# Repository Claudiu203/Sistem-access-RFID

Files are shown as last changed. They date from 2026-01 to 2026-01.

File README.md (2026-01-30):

# 🔐 Sistem de acces cu RFID (RFID Access Control System)

## 📌 Descriere generală

Acest proiect implementează un **sistem embedded de control al accesului în doi pași**, bazat pe:
- **card RFID**
- **cod PIN introdus prin tastatură 4×4**

Sistemul este realizat pe platforma **FRDM-KL25Z** și oferă autentificare sigură, feedback vizual în timp real și acționare fizică a unui mecanism de blocare. Proiectul demonstrează integrarea mai multor periferice hardware într-o arhitectură embedded modulară și scalabilă.

---

## 🎯 Obiectivele proiectului

- Implementarea unui sistem de control al accesului bazat pe **RFID + PIN**
- Integrarea interfețelor hardware: **SPI, I2C, UART, GPIO**
- Afișarea informațiilor de stare pe **OLED**
- Controlul unui **electromagnet** pentru blocare/deblocare
- Utilizarea temporizărilor neblocante prin **SysTick**
- Extinderea sistemului cu **Wi-Fi** și **loguri de evenimente**

---

## 🧠 Arhitectura sistemului

Sistemul este construit în jurul microcontrolerului **FRDM-KL25Z**, care coordonează toate modulele hardware.

### Componente hardware principale

| Componentă | Rol |
|---|-----|
| FRDM-KL25Z | Microcontroler (MCU) |
| RFID MFRC522 | Citire carduri RFID |
| Tastatură 4×4 | Introducere cod PIN |
| OLED SSD1306 | Interfață vizuală |
| LED roșu / verde | Semnalizare stare |
| Electromagnet + MOSFET | Mecanism de blocare |
| Buton fizic | Acces manual |
| Modul Wi-Fi (ESP8266) | Monitorizare în rețea |
| Modul microSD | Stocare loguri |

---

## 🔌 Interfețe utilizate

| Interfață | Componentă |
|---|---|
| SPI | RFID MFRC522, microSD |
| I2C | OLED SSD1306 |
| UART | FRDM ↔ Arduino ↔ ESP8266 |
| GPIO | Tastatură, LED-uri, electromagnet |
| SysTick | Temporizări neblocante |

---

## 🔑 Fluxul de autentificare

1. Utilizatorul apropie cardul RFID
2. UID-ul este citit și validat
3. Pe OLED apare mesajul **„Introduceți PIN”**
4. Utilizatorul introduce PIN-ul pe tastatură
5. PIN-ul este afișat în timp real
6. Sistemul validează **UID + PIN**
7. Dacă autentificarea reușește:
   - LED verde ON
   - electromagnet activ
8. După timeout → revenire în starea de repaus

---

## 🖥️ Interfața cu utilizatorul

- **OLED** – mesaje de stare (`PIN OK`, `PIN WRONG`)
- **LED verde** – acces permis
- **LED roșu** – acces blocat
- **Tastatură 4×4**
  - Cifre: introducere PIN
  - `A`: RESET PIN
  - `C`: ENTER / confirmare

---

## 🌐 Monitorizare prin Wi-Fi

Sistemul transmite mesaje de stare prin UART către un Arduino, care:
- controlează un modul **ESP8266**
- rulează un **server web local**
- afișează logurile de acces într-o pagină HTML

Funcționalități:
- monitorizare în timp real
- acces din browser
- fără servicii cloud externe

---

## 🧱 Design mecanic

Carcasa sistemului a fost proiectată în **Autodesk Fusion 360** și include:
- suport pentru placa FRDM-KL25Z
- decupaje pentru OLED, tastatură și cititor RFID
- organizare ergonomică a interfeței utilizator

Designul permite montaj stabil, mentenanță ușoară și un aspect compact.

---

## ⚙️ Tehnologii utilizate

- Limbaj: **C (bare-metal)**
- Platformă: **FRDM-KL25Z**
- CAD: **Autodesk Fusion 360**
- Comunicație: SPI, I2C, UART
- Temporizare: SysTick
- Rețea: ESP8266 (AT Commands)

---
## 👥 Autori

- Claudiu Acosti  
- Cristina Lupescu  
- Mircea Ivescu  
- Bianca Ciobanu  

**Academia Tehnică Militară „Ferdinand I” – București**

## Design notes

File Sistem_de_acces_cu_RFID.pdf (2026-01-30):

# Sistem de acces cu RFID

Claudiu Acosti
Facultatea de Sisteme Informatice ¸si Securitate Cibernetic˘a Academia Tehnic˘a Militar˘a „Ferdinand I” Bucure¸sti, România
claudiu.acosti@mta.ro

Cristina Lupescu
Facultatea de Sisteme Informatice ¸si Securitate Cibernetic˘a Academia Tehnic˘a Militar˘a „Ferdinand I” Bucure¸sti, România
cristina.lupescu@mta.ro

Mircea Ivescu
Facultatea de Sisteme Informatice ¸si Securitate Cibernetic˘a Academia Tehnic˘a Militar˘a „Ferdinand I” Bucure¸sti, România
mircea.ivescu@mta.ro

Bianca Ciobanu
Facultatea de Sisteme Informatice ¸si Securitate Cibernetic˘a Academia Tehnic˘a Militar˘a „Ferdinand I” Bucure¸sti, România
bianca.ciobanu@mta.ro

Rezumat—Acest proiect prezinta dezvoltarea unui sistem elec- ˘ tronic inteligent de control al accesului, realizat pe platforma FRDM-KL25Z s,

i bazat pe identificare prin radiofrecvent,a˘
(RFID). Sistemul utilizeaza un modul RFID pentru citirea s ˘ | | | , i
autentificarea cardurilor, completat de o tastatura 4×4 pentru ˘ introducerea unui cod PIN secundar, crescând astfel nivelul de securitate printr-o verificare în doi pas,
i. Cifrele introduse de
utilizator prin tastatura sunt afis ˘ | ,ate în timp real pe un ecran
OLED, care este folosit s,

i pentru prezentarea mesajelor de stare s,

i a interfet,ei cu utilizatorul, facilitând operarea s,
i diagnosticarea
sistemului. Doua LED-uri asigur ˘ | a semnalizarea vizual ˘ | a rapid ˘ | a˘
asupra validitat˘ ,

ii autentificarii (acces permis / acces refuzat). ˘ Mecanismul fizic de blocare este implementat cu ajutorul unui electromagnet, activat numai dupa validarea cu succes a cardului ˘ RFID s,

i a codului PIN.
Pentru extinderea funct, | ionalitat˘ ,
ilor, proiectul include un mo-
dul Wi-Fi, ce permite transmiterea datelor catre o ret ˘ | ,ea locala˘
sau infrastructura cloud pentru monitorizarea accesului în timp ˘ real, precum s,

i un modul microSD pentru stocarea locala a ˘ logurilor de evenimente. Integrarea acestor componente conduce la un sistem modular, scalabil s,

i eficient energetic, reprezentând o solut,

ie moderna s ˘ ,

i sigura de control al accesului pentru aplicat ˘ | ,
| | | ii
rezident,

iale s,

i industriale. Pentru vizualizarea proiectului prezentat se poate accesa https://github.com/Claudiu203/Sistem-access-RFID.
Index Terms—RFID, controlul accesului, sisteme embedded, FRDM-KL25Z, securitate.
I. INTRODUCERE

Sistemele moderne de control al accesului reprezinta o ˘
componenta esent ˘ | ,
iala în cres ˘ | ,
terea nivelului de securitate pentru
cladiri, laboratoare, zone industriale sau spat ˘ | ,
ii rezident,

iale.
În contextul dezvoltarii accelerate a tehnologiilor embedded ˘ s,

i IoT, solut,

iile de identificare inteligenta devin tot mai ac- ˘ cesibile, mai flexibile s,

i mai sigure. Una dintre tehnologiile
utilizate pe scara larg ˘ | a este identificarea prin radiofrecvent ˘ | ,a˘
(RFID), care permite autentificarea rapida s ˘ ,

i far˘ a contact a ˘
utilizatorilor, asigurând un nivel ridicat de confort s,
| | i fiabilitate.
Proiectul de fat,a propune realizarea unui sistem electronic ˘ integrat de control al accesului utilizând platforma FRDM-KL25Z, un microcontroler performant s,
| | i versatil, potrivit
Acronim | Denumire
RFID | Radio Frequency Identification
PIN | Personal Identification Number
OLED | Organic Light Emitting Diode
LED | Light Emitting Diode
MCU | Microcontroller Unit
SPI | Serial Peripheral Interface
I2C | Inter-Integrated Circuit
UART | Universal Asynchronous Receiver-Transmitter
GPIO | General Purpose Input/Output
UID | Unique Identifier
SD | Secure Digital
Wi-Fi | Wireless Fidelity
FRDM | Freedom Development Platform
MOSFET | Metal-Oxide-Semiconductor Field-Effect Transistor
SysTick | System Timer Tick
Tabela I
LISTA ACRONIMELOR UTILIZATE

aplicat,

iilor embedded de nivel mediu-complex. Sistemul com-
bina autentificarea pe baz ˘ | a de card RFID cu introducerea unui ˘
cod PIN prin intermediul unei tastaturi 4×4, asigurând un mecanism de securitate în doi pas,
i. Pentru interact,

iunea cu
utilizatorul, un afis, aj OLED este utilizat atât pentru vizualizarea în timp real a cifrelor introduse, cât s,

i pentru afis, area
mesajelor s,

i starilor sistemului. ˘

Elementele hardware auxiliare, precum LED-urile de semnalizare s,

i electromagnetul utilizat pentru mecanismul de
blocare, completeaza partea funct ˘ | ,

ionala a sistemului, oferind ˘ feedback vizual s,

i act,

ionare fizica a us ˘ ,

ii. În plus, integrarea
unui modul Wi-Fi permite transmiterea datelor de acces catre ˘ o ret,ea sau un server extern, facilitând monitorizarea de
la distant,a, iar modulul microSD ofer ˘ | a posibilitatea stoc ˘ | arii ˘
locale a logurilor s, | i a evenimentelor de securitate.

Prin combinat,

ia acestor componente, proiectul demonstreaza modul în care un sistem embedded poate implementa ˘ o solut,

ie moderna, sigur ˘ a s ˘ ,

i extensibila de control al accesului, ˘
adaptabila unei game largi de aplicat ˘ | ,
| ii practice.

A. Contextul general al temei

Controlul accesului în spat,

ii securizate reprezinta o nece- ˘
sitate tot mai importanta în contextul cres ˘ | ,
terii cerint,elor de
securitate fizica. Metodele tradit ˘ | ,
ionale bazate pe chei mecanice sau cartele simple prezinta limit ˘ ari semnificative, precum ˘ riscul de pierdere, copiere sau utilizare neautorizata. În plus, ˘ aceste solut,

ii nu ofera un mecanism eficient de monitorizare ˘ s,

i nici un feedback clar catre utilizator. ˘
În acest context, sistemele embedded de control al accesului,
bazate pe tehnologii far˘ a contact precum RFID s ˘ | ,
| | i autentificare
suplimentara prin cod PIN, devin solut ˘ | ,
ii moderne, flexibile s,

i
scalabile. Proiectul de fat,a se încadreaz ˘ | a în aceast ˘ | a categorie, ˘
propunând o implementare practica a unui sistem de acces ˘ inteligent, realizat pe platforma FRDM-KL25Z.
B. Motivat,ia alegerii proiectului
Alegerea acestui proiect a fost determinata de dorint ˘ | ,a
de a realiza un sistem embedded complet, care sa inte- ˘ greze mai multe tipuri de interfet,e hardware s,
| | i protocoale
de comunicat,
ie. Sistemul combina comunicat ˘ | ,
| | ii SPI (pentru
RFID), I2C (pentru OLED), GPIO (pentru tastatura, LED- ˘ uri, buton s,

i electromagnet) s,

i mecanisme de temporizare prin SysTick.
Proiectul ofera o imagine de ansamblu asupra modului în ˘ care un microcontroler poate coordona simultan mai multe periferice s,
i poate implementa o logica de securitate real ˘ | a,˘
utilizata în aplicat ˘ | ,
ii de control al accesului folosind exclusiv placuta frdm-kl25z.
C. Utilitatea solut,iei propuse

Solut,

ia propusa automatizeaz ˘ | a procesul de autentificare s ˘ | ,
i
acces, reducând intervent,
ia umana direct ˘ | a s ˘ ,
| | i crescând nivelul
de securitate. Sistemul permite accesul doar în urma validarii ˘ a doi factori: cardul RFID s,

i codul PIN introdus de utilizator. Feedback-ul este oferit prin LED-uri s,

| | i mesaje afis, ate pe
ecranul OLED, ceea ce îmbunat˘ at˘,es,
te experient,a de utilizare s,

i claritatea interact,

iunii.
Prin integrarea modulelor Wi-Fi s,

i microSD, sistemul poate
fi extins pentru monitorizarea accesului de la distant,a s ˘ , i
stocarea locala a evenimentelor, ceea ce îl face potrivit pentru ˘ aplicat,

ii reale.

D. Domenii de aplicare

Sistemul dezvoltat poate fi adaptat pentru multiple scenarii practice, precum:
- controlul accesului în cladiri de birouri sau institut ˘ | | , ii
publice;
- acces securizat în laboratoare universitare sau industriale;
- sisteme de acces pentru campusuri, camine sau zone ˘ rezident,

iale;
- integrarea în solut,

ii de tip smart home sau smart building.

E. Exemple de dispozitive similare

Sistemele comerciale moderne de control al accesului utilizeaza frecvent autentificarea prin card RFID sau tag NFC, ˘ combinata cu introducerea unui cod PIN pentru un nivel supli- ˘ mentar de securitate. În mediul educat,
ional s,

i de prototipare,
platforme precum Arduino, ESP32 sau placi din seria NXP ˘ FRDM sunt utilizate pentru dezvoltarea de sisteme similare, care includ cititoare RFID, tastaturi matriceale, afis, aje s,

i
mecanisme electromecanice de blocare.
F. Obiectivele proiectului

Principalele obiective ale proiectului sunt:
- proiectarea s,

i realizarea unui sistem embedded de control al accesului bazat pe RFID s,

i cod PIN;
- integrarea mai multor interfet,e hardware (SPI, I2C, GPIO) într-o aplicat,

ie unitara;˘
- implementarea unui mecanism de autentificare în doi pas,

i
(card + PIN);
- afis, area în timp real a informat,

iilor relevante pe un ecran OLED;
- realizarea unui sistem de semnalizare vizuala cu LED-uri ˘ pentru starea accesului;
- controlul unui electromagnet pentru blocarea/deblocarea mecanismului de acces;
- utilizarea temporizarilor neblocante prin intermediul ti- ˘ merului SysTick;
- posibilitatea extinderii sistemului prin conectivitate Wi-Fi s,

i stocare pe microSD.

II. ARHITECTURA S,
I DESIGNUL SISTEMULUI
Arhitectura sistemului de control al accesului este con-
ceputa într-o manier ˘ | a modular ˘ | a, pentru a facilita integrarea ˘
mai multor componente hardware distincte s,

i gestionarea lor
printr-un flux logic bine definit. Sistemul este construit în jurul microcontrolerului FRDM-KL25Z, care act,

ioneaza ca ˘
unitate centrala de control s ˘ | ,
i coordoneaza comunicat ˘ | ,
ia dintre
modulele periferice prin interfet,e precum SPI, I2C, UART s,

i
GPIO.
Structura aplicat,

iei este organizata pe straturi logice, in- ˘ cluzând: nivelul hardware, nivelul de abstractizare a driverelor, modulul de logic˘a aplicativ˘a s,

i interfat,a cu utilizatorul.
Aceasta abordare permite scalabilitate crescut ˘ | a, mentenant ˘ | ,a˘
us, oara s ˘ ,
i posibilitatea extinderii ulterioare cu funct,

ionalitat˘,
i
suplimentare.
A. Componentele majore ale sistemului
Sistemul este alcatuit din urm ˘ | atoarele componente princi- ˘
pale:
- Placa de dezvoltare FRDM-KL25Z – unitatea centrala˘ de control (MCU) care coordoneaza toate modulele har- ˘ dware s,

i executa logica sistemului de acces; ˘
- Modulul RFID MFRC522 – utilizat pentru citirea cardurilor RFID s,

i obt,

inerea identificatorului unic (UID) al utilizatorului;
- Tastatura matriciala 4×4 ˘ – permite introducerea codului PIN, reprezentând al doilea factor de autentificare;
- Afis, aj OLED SSD1306 – interfat,a vizual ˘ | a pentru afis ˘ | , area
mesajelor de stare, a instruct,

iunilor s,

i a PIN-ului introdus;

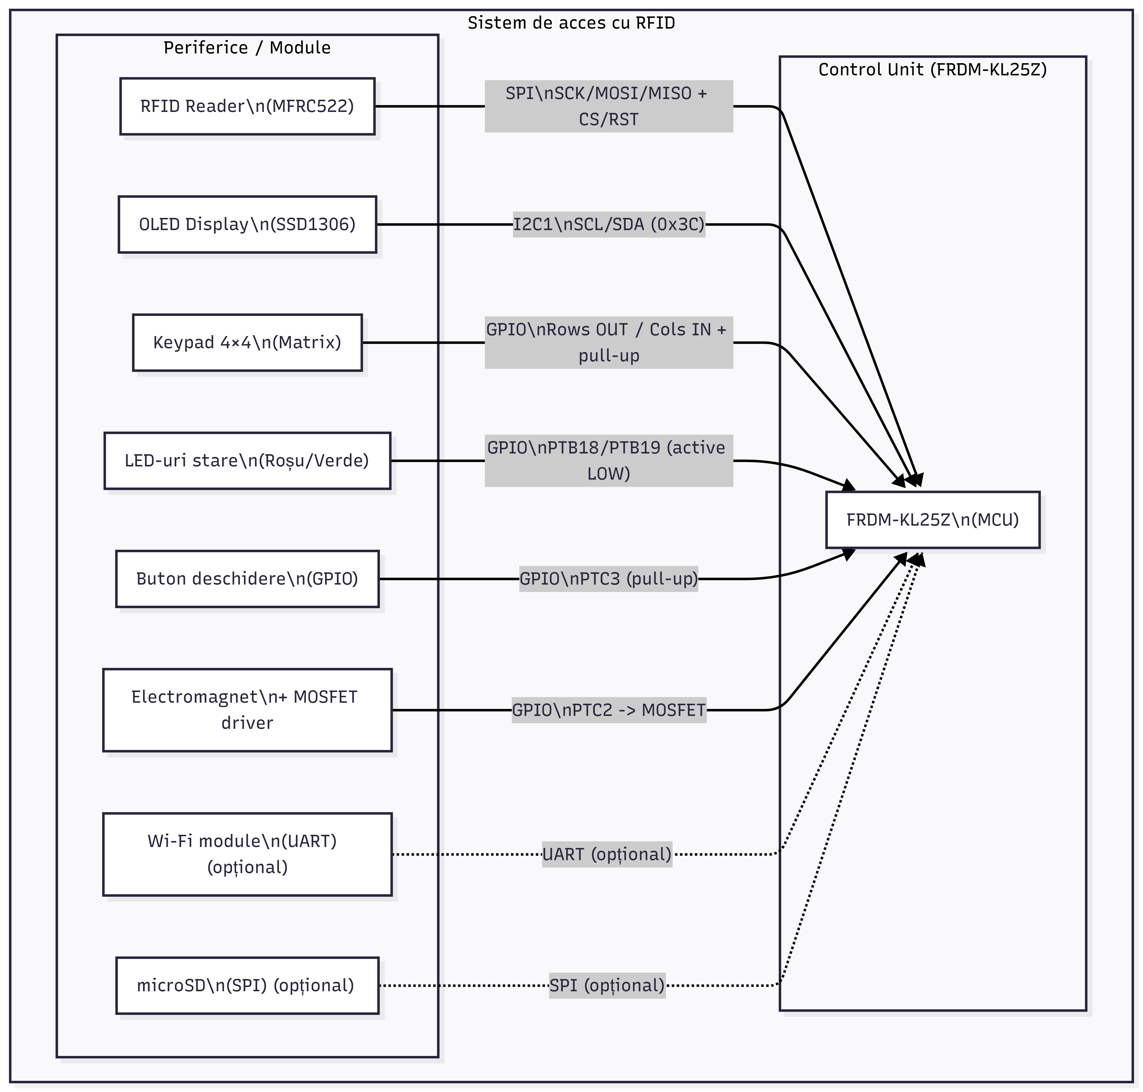
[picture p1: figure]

Figura 1. Diagrama de componente a arhitecturii hardware a sistemului de ˘ control al accesului bazat pe RFID

- Electromagnet de blocare – elementul de act, ionare
mecanica ce permite blocarea s ˘ | ,
i deblocarea us,

ii;
- Driver cu MOSFET pentru electromagnet – circuit de comanda care permite controlul unei sarcini inductive de ˘ putere prin intermediul unui pin GPIO al microcontrolerului;
- LED-uri de stare (ros,u s,

i verde) – ofera feedback ˘ vizual rapid privind starea sistemului (acces permis / acces refuzat);
- Buton fizic de deschidere – permite act,
ionarea manuala˘
a mecanismului de acces în anumite scenarii;
- Modul Wi-Fi – asigura posibilitatea transmiterii datelor ˘
de acces catre o ret ˘ | ,ea sau un server extern pentru moni-
torizare;
- Modul microSD – utilizat pentru stocarea locala a logu- ˘ rilor de acces s,

i a evenimentelor generate de sistem.

B. Interact,iunea dintre module
Fiecare componenta hardware comunic ˘ | a cu microcontrole- ˘
rul printr-o interfat,a dedicat ˘ | a:˘
- RFID MFRC522 – interfat,a˘ SPI;
- microSD – interfat,a˘ SPI;
- OLED – interfat,a˘ I2C (sau SPI, în funct,
| | ie de versiune);
- Tastatura 4×4 – ˘ | GPIO configurat în mod scan matrix;
- Electromagnet – GPIO + driver MOSFET;
- Wi-Fi – interfat,a˘ UART.
Fluxul general al sistemului urmeaza o mas ˘ | ,
ina de st ˘ | ari ce ˘
gestioneaza citirea cardului, introducerea PIN-ului, validarea ˘ s,

i act,

ionarea electromagnetului.

C. Diagram˘a bloc a arhitecturii sistemului
În Figura 1 este prezentata o schem ˘ | a bloc ce ilustreaz ˘ | a˘
conexiunile dintre module.

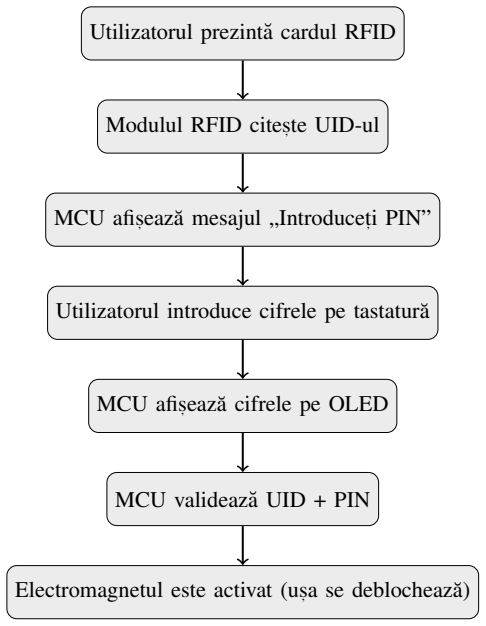
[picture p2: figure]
Utilizatorul prezinta cardul RFID ˘; Modulul RFID cites,; te UID-ul; MCU afis, eaza mesajul „Introducet ˘; i PIN”; Utilizatorul introduce cifrele pe tastatura˘; MCU afis, eaza cifrele pe OLED ˘; MCU valideaza UID + PIN ˘

Electromagnetul este activat (us, a se deblocheaza)˘

Figura 2. Flux compact al procesului de autentificare RFID + PIN

D. Diagram˘a de secvent,˘a a procesului de autentificare Pentru a ilustra interact,

iunea dintre module în timpul au-
tentificarii, este prezentat ˘ | a urm ˘ | atoarea diagram ˘ | a de secvent ˘ | ,a˘
simplificata:˘

III. INTEGRAREA MODULULUI RFID MFRC522 CU
PLATFORMA FRDM-KL25Z
Identificarea utilizatorilor în cadrul sistemului de control al accesului este realizata cu ajutorul modulului RFID ˘
MFRC522, un cititor RFID de joasa frecvent ˘ | ,a, compatibil cu ˘
carduri pasive, utilizat pe scara larg ˘ | a în aplicat ˘ | ,
ii embedded.
Modulul permite autentificarea rapida s ˘ ,

i far˘ a contact, fiind ˘
potrivit pentru sisteme de acces datorita costului redus, con- ˘
sumului scazut de energie s ˘ | ,
i us, urint,ei în integrare.
A. Interfat,a de comunicat,ie s,i conexiunile hardware Comunicarea dintre microcontrolerul FRDM-KL25Z s,
| | | | i mo-
dulul MFRC522 se realizeaza prin interfat ˘ | ,a SPI (Serial Pe-
ripheral Interface), aleasa pentru fiabilitatea s ˘ | ,
| | | | i viteza sa.
Conexiunile hardware implementate în cadrul proiectului sunt prezentate mai jos:
- SCK (Serial Clock) – conectat la pinul PTC5, configurat ca SPI clock;
- MOSI (Master Out Slave In) – conectat la pinul PTC6, utilizat pentru transmiterea datelor catre modulul RFID; ˘
- MISO (Master In Slave Out) – conectat la pinul PTC7, utilizat pentru recept,

ia datelor de la modulul RFID;
- CS (Chip Select / SDA) – conectat la pinul PTC4, configurat ca GPIO s,

i controlat manual;
- RST (Reset) – conectat la pinul PTA1, utilizat pentru resetarea modulului MFRC522;
- VCC – alimentare la 3.3V, conform cerint,elor modulului;

- GND – masa comun ˘ | a cu microcontrolerul. ˘
Linia CS nu este gestionata automat de perifericul SPI al mi- ˘ crocontrolerului, ci este controlata manual din software, fiind ˘ activata (nivel logic LOW) strict pe durata transferurilor SPI. ˘
Aceasta abordare ofer ˘ | a un control precis asupra comunicat ˘ | ,
iei
s,
i elimina erorile cauzate de sincronizarea incorect ˘ | a a semna- ˘
lului de select,

ie.

B. Configurarea modulului RFID
Dupa realizarea conexiunilor hardware, modulul MFRC522 ˘ este init,
ializat software printr-o secvent,a de configur ˘ | ari reco- ˘
mandate în datasheet. Acestea includ setarea timerelor interne, a modului de transmisie s,

i activarea antenei RF. Comunicat,

ia
SPI este configurata în ˘ Mode 0 (CPOL = 0, CPHA = 0), iar frecvent,a este ment,

inuta sub 1 MHz pentru a asigura ˘ stabilitatea comunicat,

iei, în special în cazul utilizarii firelor ˘ de tip jumper.
Resetarea modulului se realizeaza printr-un pin GPIO dedi- ˘ cat, asigurând init,

ializarea corecta la pornirea sistemului. ˘

C. Probleme întâmpinate în implementare
În procesul de dezvoltare au fost identificate mai multe dificultat˘,
i practice. Una dintre principalele probleme a fost le-
gata de gestionarea semnalului Chip Select. Utilizarea init ˘ | ,

iala˘
a controlului automat al CS de catre perifericul SPI a condus la ˘
lipsa raspunsurilor valide din partea modulului RFID. Aceast ˘ | a˘
problema a fost rezolvat ˘ | a prin controlul manual al CS ca pin ˘
GPIO.
O alta problem ˘ | a a fost reprezentat ˘ | a de detect ˘ | ,
iile false ale
cardurilor RFID. Init,
| | ial, sistemul interpreta gres, | it anumite flag-
uri de întrerupere, ceea ce ducea la semnalarea prezent,ei unui card chiar s,

i în absent,a acestuia. Solut,

ia adoptata a constat în ˘
verificarea explicita a existent ˘ | ,ei unui raspuns valid în FIFO-ul ˘
modulului MFRC522, conform protocolului REQA.
D. Detect,ia cardului s,i semnalizarea accesului
Detect,

ia unui card RFID se realizeaza prin trimiterea co- ˘ menzii REQA, utilizata pentru identificarea cardurilor aflate ˘ în apropierea antenei. În momentul în care modulul RFID primes,

te un raspuns valid, microcontrolerul interpreteaz ˘ | a acest ˘
eveniment ca o autentificare init,

iala reus ˘ ,

ita.˘
Ca feedback vizual pentru utilizator, LED-ul verde integrat pe placa FRDM-KL25Z este aprins, indicând detectarea cardului. Simultan, electromagnetul care controleaza mecanismul ˘ fizic de acces este activat. Atât LED-ul verde, cât s,

i electro-
magnetul ramân active pentru o durat ˘ | a de ˘ | 5 secunde, dupa˘
care sistemul revine automat în starea de repaus, cu accesul blocat.
Aceasta temporizare contribuie la cres ˘ | ,
| | | terea sigurant,ei sis-
temului s, | i previne ment,

inerea accesului deschis pentru o
perioada nedeterminat ˘ | a.˘

IV. INTEGRAREA TASTATURII 4×4 PENTRU INTRODUCEREA CODULUI PIN

Pentru cres,

terea nivelului de securitate, sistemul implementeaza un al doilea factor de autentificare prin intermediul unei ˘ tastaturi matriceale 4×4, utilizata pentru introducerea unui cod ˘
PIN numeric. Aceasta metod ˘ | a adaug ˘ | a un nivel suplimentar de ˘
protect,
ie fat,a de autentificarea exclusiv ˘ | a prin card RFID. ˘
A. Conectarea hardware

Tastatura este organizata sub forma unei matrice de 4 ˘ rânduri s,

i 4 coloane, fiecare linie fiind conectata la pini GPIO ˘ ai microcontrolerului FRDM-KL25Z:
- Rânduri (outputs): PTD5, PTD0, PTD2, PTD3
- Coloane (inputs cu pull-up): PTD7, PTA13, PTE0, PTE1

Rândurile sunt configurate ca ies,

iri digitale, iar coloanele
ca intrari cu rezistent ˘ | ,e interne de pull-up activate. Astfel, în
starea de repaus, toate coloanele se afla în nivel logic HIGH. ˘
B. Principiul de funct,ionare

Citirea tastaturii se face prin tehnica row scanning. Pe rând, fiecare linie este adusa la nivel logic LOW, iar coloanele sunt ˘ citite pentru a detecta daca una dintre ele devine LOW, semn ˘
ca tasta corespunz ˘ | atoare intersect ˘ | ,
iei rând–coloana este ap ˘ | asat ˘ | a.˘
Pentru eliminarea efectului de debounce, este introdus un
mic timp de întârziere software dupa detectarea unei ap ˘ | as˘ ari, ˘
urmat de as,

teptarea eliberarii tastei înainte de a continua ˘ scanarea.

C. Maparea tastelor s,i logica PIN
Fiecarei combinat ˘ | ,

ii rând–coloana îi corespunde un caracter ˘ (0–9, A–F). În cadrul aplicat,
iei:
- Tastele numerice sunt folosite pentru introducerea PINului
- Tasta A are rol de RESET (s,
terge PIN-ul introdus)
- Tasta C are rol de ENTER (confirma PIN-ul) ˘

PIN-ul este stocat într-un buffer de 4 caractere s,

i comparat
cu un cod prestabilit în firmware. În funct,
ie de rezultat,
sistemul afis, eaza un mesaj corespunz ˘ | ator pe OLED s ˘ | ,

i comanda˘
LED-urile s,

i electromagnetul.

V. INTERFAT, A DE AFIS, ARE OLED (SSD1306)

Pentru interact,

iunea vizuala cu utilizatorul, sistemul uti- ˘
lizeaza un afis ˘ | , aj OLED monocrom controlat de driverul
SSD1306. Acesta este folosit pentru afis, area codului PIN introdus, a mesajelor de stare s,

i a feedback-ului sistemului.

A. Conectarea hardware s,i interfat,a de comunicat,ie

Afis, ajul OLED comunica cu microcontrolerul prin magis- ˘ trala I2C1, utilizând urmatorii pini: ˘

- SCL – PTC10
- SDA – PTC11

Adresa I2C utilizata este ˘ 0x3C. Liniile sunt configurate în mod open-drain, conform cerint,elor protocolului I2C.

B. Init,ializarea afis, ajului
La pornirea sistemului, afis, ajul este init,

ializat printr-o
secvent,a de comenzi care configureaz ˘ | a:˘
- modul de adresare a memoriei grafice
- contrastul
- orientarea imaginii
- activarea sursei interne de tensiune pentru panou Dupa init ˘ ,
ializare, ecranul este s,

ters complet.

C. Afis, area informat,iilor
Afis, ajul este utilizat pentru:
- afis, area textului „PIN:” urmat de caractere mascate sau cifre
- afis, area mesajelor temporare: „PIN OK” sau „PIN WRONG”
Mesajele temporare sunt afis, ate pentru o durata limitat ˘ | a,˘
gestionata printr-un timer software bazat pe SysTick, dup ˘ | a care ˘
sunt s,
terse automat far˘ a a afecta restul interfet ˘ | | ,ei.
VI. SEMNALIZAREA VIZUALA CU ˘ | LED-URI
Sistemul utilizeaza dou ˘ | a LED-uri pentru semnalizarea ra- ˘
pida a st ˘ | arii autentific ˘ | arii: ˘
- LED ros,u – indica starea de repaus / acces blocat ˘
- LED verde – indica autentificare reus ˘ | ,
ita˘
LED-urile sunt conectate la pinii PTB18 (ros, u) s,
| | | i PTB19
(verde) s,

i sunt configurate în mod active LOW. Astfel, aprinderea LED-ului se face prin setarea pinului la nivel logic LOW.
Dupa o autentificare reus ˘ | ,
ita, LED-ul verde r ˘ | amâne aprins ˘
timp de 3 secunde, temporizare realizata cu ajutorul unui ˘ contor incrementat de întreruperea SysTick.

VII. CONTROLUL ELECTROMAGNETULUI DE BLOCARE
Mecanismul fizic de blocare a us,

ii este realizat cu ajutorul unui electromagnet comandat de microcontroler.

A. Conectarea hardware
Electromagnetul este controlat prin pinul PTC2, conectat la un tranzistor de putere (MOSFET) care permite alimentarea
sarcinii de curent mai mare. Aceasta configurat ˘ | ,
| | | ie protejeaza˘
microcontrolerul s,

i permite comanda unei sarcini inductive.

B. Modul de operare
Electromagnetul este activat simultan cu LED-ul verde,
în cazul unei autentificari valide. El r ˘ | amâne activ pe durata ˘
ferestrei de acces (3 secunde), dupa care este dezactivat ˘
automat. Sincronizarea este realizata prin acelas ˘ | ,
| | | i mecanism
de temporizare utilizat pentru LED-uri.

VIII. BUTONUL FIZIC DE DESCHIDERE
Pe lânga autentificarea electronic ˘ | a, sistemul include un ˘
buton fizic conectat la pinul PTC3, configurat ca intrare cu
rezistent,a intern ˘ | a de pull-up. ˘
Apasarea butonului aduce pinul la nivel logic LOW s ˘ | ,
| | | i este
interpretata ca o cerere de deschidere manual ˘ | | a. La detectare, ˘
sistemul activeaza LED-ul verde s ˘ | ,
i electromagnetul pentru
aceeas,
i perioada temporizat ˘ | a, oferind o metod ˘ | a alternativ ˘ | a de ˘
acces (de exemplu pentru personal autorizat).

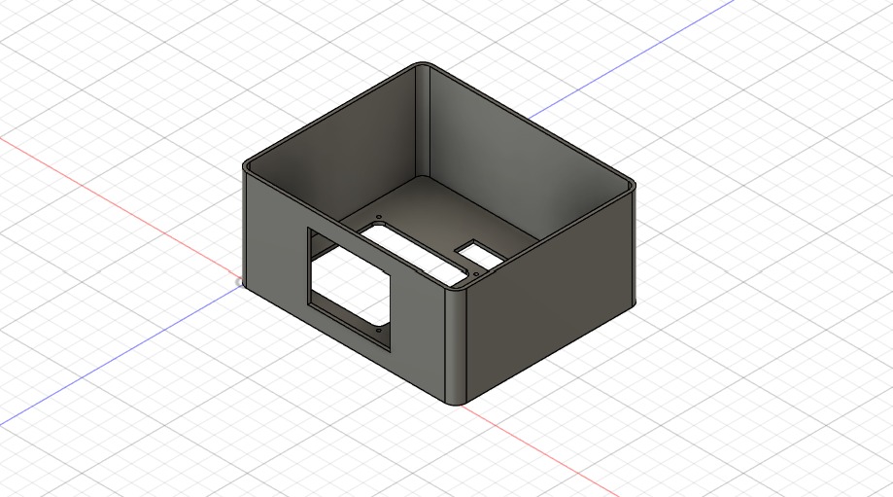
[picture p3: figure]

Figura 3. Model 3D al carcasei realizat în Autodesk Fusion 360 pentru integrarea sistemului de control al accesului

IX. GESTIONAREA TIMPULUI CU SYSTICK
Pentru implementarea temporizarilor f ˘ | ar˘ a a bloca execut ˘ | ,
ia
principala, sistemul utilizeaz ˘ | a timerul ˘ | SysTick al microcon-
trolerului. Acesta genereaza o întrerupere la fiecare 1 ms, ˘ incrementând un contor global de milisecunde.
Aceasta baz ˘ | a de timp este utilizat ˘ | a pentru: ˘
- ment,

inerea LED-ului verde activ pentru o perioada fix ˘ a˘
- controlul duratei de activare a electromagnetului
- afis, area temporara a mesajelor pe OLED ˘
- implementarea întârzierilor scurte pentru debounce
Aceasta abordare permite realizarea unui sistem reactiv, f ˘ | ar˘ a˘
utilizarea buclelor lungi de tip delay blocant.
X. PROIECTAREA COMPONENTELOR MECANICE ÎN AUTODESK FUSION 360
Pe lânga partea electronic ˘ | a s ˘ ,
i software, proiectul a inclus s,

i realizarea componentelor mecanice necesare montarii ˘ sistemului de control al accesului. Pentru modelarea 3D a acestor componente a fost utilizat software-ul Autodesk Fusion 360, un mediu profesional de proiectare asistata de calculator ˘ (CAD), utilizat pentru dezvoltarea de ansambluri mecanice s,

i
prototipuri, cum se poate observa in Figura 3 si Figura 4. Au fost proiectate elemente precum carcasa principala a ˘ sistemului, suporturile pentru modulele electronice (RFID,
OLED, tastatura, plac ˘ | a FRDM-KL25Z), precum s ˘ | ,
i elementele
de fixare s,

i ghidare a cablurilor. Modelarea 3D a permis verificarea pozit,

ionarii corecte a componentelor, optimizarea ˘ spat,

iului interior s,

i asigurarea unei integrari mecanice stabile ˘ s,

i sigure.
Utilizarea Fusion 360 a facilitat simularea ansamblului complet înainte de realizarea fizica a prototipului, reducând ˘ riscul de erori de montaj s,

i permit,ând ajustari rapide ale ˘ designului.

A. Designul interfet,ei fizice a utilizatorului O atent,
ie speciala a fost acordat ˘ | a zonei de interact ˘ | ,
iune cu
utilizatorul. Carcasa frontala a fost proiectat ˘ | a pentru a integra ˘
cititorul RFID, tastatura pentru introducerea codului PIN s,

i
afis, ajul OLED într-un mod intuitiv s,

i ergonomic.
Dispunerea elementelor a fost gândita astfel încât utiliza- ˘
torul sa poat ˘ | a apropia cardul, introduce codul s ˘ | ,
i vizualiza

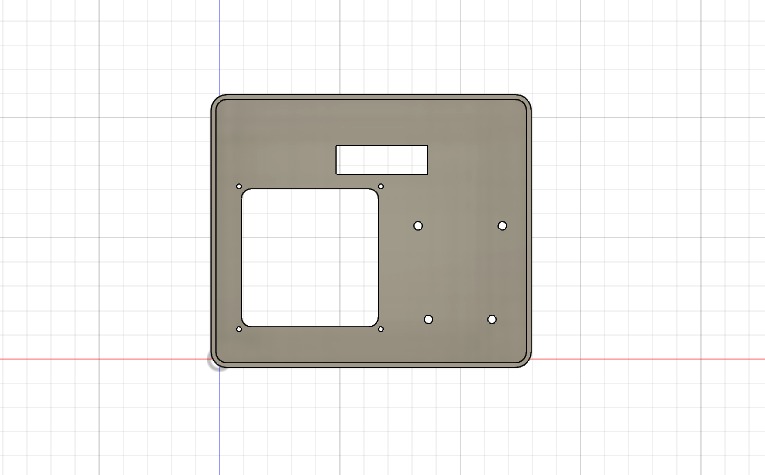
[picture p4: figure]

Figura 4. Model 3D al structurii mecanice realizat în Autodesk Fusion 360 pentru integrarea sistemului de control al accesului din fata

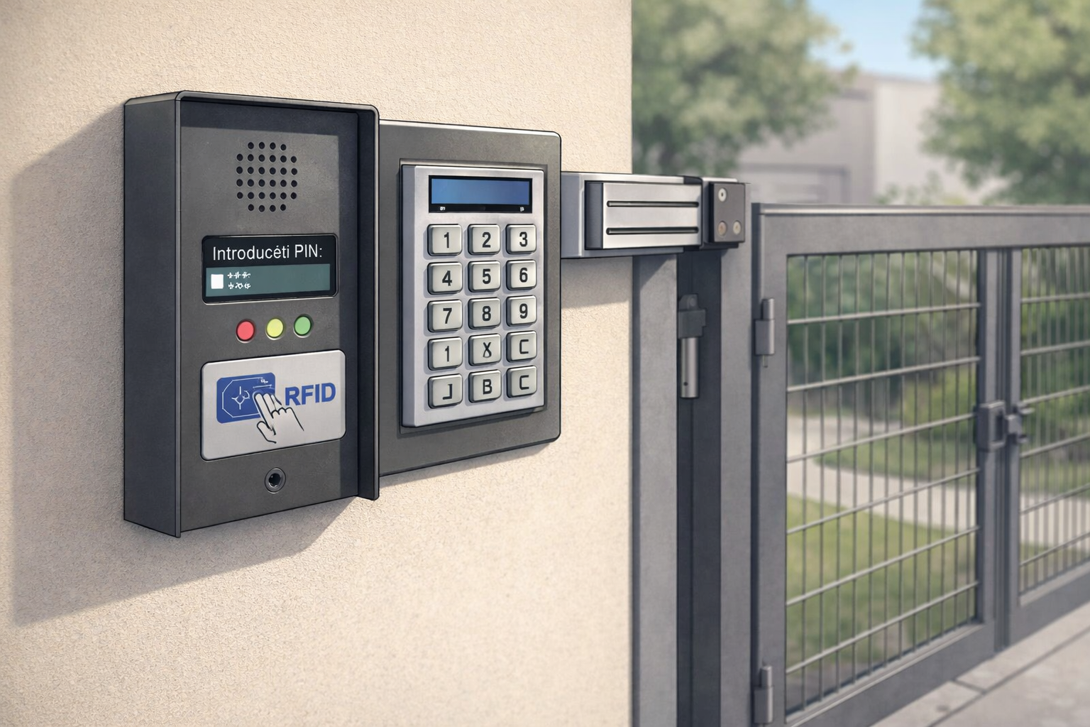
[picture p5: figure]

Figura 5. Randare ilustrativa a interfet ˘ | ,ei fizice a sistemului de acces cu RFID
s,

i tastatura PIN ˘

mesajele de stare într-o succesiune naturala a act ˘ ,

iunilor. În
Figura 5 este prezentata o randare ilustrativ ˘ | a a modului în ˘
care este organizata interfat ˘ | ,a fizica a sistemului de control al ˘
accesului.

XI. FLUXUL COMPLET DE FUNCT,
IONARE AL SISTEMULUI
Funct,
ionarea sistemului poate fi descrisa ca o bucl ˘ | a continu ˘ | a˘
de monitorizare a intrarilor s ˘ | ,
i actualizare a ies, | irilor.
A. Starea de repaus
În mod normal:
- LED-ul ros, u este aprins
- electromagnetul este dezactiv
B. Scenariul de autentificare
1) Sistemul detecteaza apropierea unui card RFID. ˘
2) LED-ul verde s,

i electromagnetul sunt activate temporar.
3) Utilizatorul introduce codul PIN pe tastatura.˘
4) PIN-ul este afis, at pe OLED în timp real.
5) La apasarea tastei ENTER: ˘
- daca PIN-ul este corect ˘ | → se afis, eaza „PIN OK”, ˘
acces permis
- daca PIN-ul este gres ˘ | ,

it → se afis, eaza „PIN ˘
WRONG”, acces refuzat
C. Sincronizarea componentelor
Interfat,a fizica a utilizatorului reprezint ˘ | a punctul principal ˘
de interact,

iune dintre sistemul de control al accesului s,

i
persoana care solicita accesul. Din acest motiv, proiectarea ˘ acestei zone a avut un rol esent,

ial atât din punct de vedere funct,

ional, cât s,

i ergonomic. Obiectivul a fost realizarea unei interfet,e intuitive, us, or de utilizat s,

i clara din punct de vedere ˘ vizual, astfel încât utilizatorul sa poat ˘ a parcurge procesul de ˘ autentificare într-un mod natural s,

i far˘ a ambiguit ˘ | at˘,
i.
Carcasa frontala a fost conceput ˘ | a pentru a integra cele trei ˘
elemente principale ale interact,

iunii cu utilizatorul: cititorul RFID, tastatura pentru introducerea codului PIN s,

i afis, ajul
OLED pentru feedback vizual. Dispunerea acestor componente a fost realizata t ˘ ,

inând cont de ordinea logica a pas ˘ , ilor de
autentificare. Astfel, zona de apropiere a cardului RFID este pozit,
ionata în partea superioar ˘ | a, urmat ˘ | a de afis ˘ | , ajul OLED, iar
tastatura numerica este amplasat ˘ | a în partea inferioar ˘ | a, într-o ˘
zona us ˘ , or accesibila pentru introducerea codului PIN. ˘
Aceasta organizare vertical ˘ | a reflect ˘ | a fluxul real de utilizare ˘
al sistemului: utilizatorul apropie mai întâi cardul de cititor, apoi prives,

te afis, ajul pentru instruct,

iuni sau confirmari, iar ul- ˘ terior introduce codul PIN folosind tastatura. Prin aceasta abor- ˘
dare, mis, carile utilizatorului sunt naturale, iar interact ˘ | ,
iunea cu
sistemul devine intuitiva chiar s ˘ | ,
i pentru persoane care nu sunt familiarizate cu dispozitivele electronice.
În proiectarea carcasei s-a acordat o atent, ie deosebita di- ˘
mensiunilor s,

i spat,

iului necesar fiecarei componente. Afis ˘ | , ajul
OLED necesita o fereastr ˘ | a frontal ˘ | a precis decupat ˘ | a, astfel încât ˘
informat,
iile afis, ate sa fie vizibile f ˘ | ar˘ a a expune componentele ˘
interne. Tastatura a fost pozit,
ionata într-o zon ˘ | a plan ˘ | a, pentru ˘
a asigura apasarea confortabil ˘ | a a tastelor, iar zona cititorului ˘
RFID a fost lasat ˘ | a liber ˘ | a de obstacole pentru a nu afecta ˘
câmpul electromagnetic necesar detectarii cardurilor. ˘
Din punct de vedere estetic, interfat,a fizica a fost gândit ˘ | a˘
sa aib ˘ | a un aspect compact s ˘ | ,

i ordonat, cu o separare clara între ˘ zonele funct,

ionale. Carcasa ofera protect ˘ | ,

ie mecanica compo- ˘
nentelor electronice, ascunzând cablurile s,

i circuitele interne,
ceea ce contribuie la un aspect profesional al prototipului. În acelas,
i timp, designul permite accesul facil la componente
pentru mentenant,a sau modific ˘ | ari ulterioare. ˘
Ergonomia a fost un alt factor important în procesul de proiectare. Înalt ˘ ,
imea s,

i înclinarea panoului frontal au fost alese
astfel încât utilizatorul sa poat ˘ | a citi us ˘ | , or mesajele de pe afis, aj
s,
i sa introduc ˘ | a PIN-ul f ˘ | ar˘ a efort, indiferent de pozit ˘ | ,
ia în care
este montat sistemul (de exemplu, pe un perete sau lânga o ˘
us, a). Butoanele tastaturii sunt suficient de distant ˘ | ,ate pentru a
preveni apas˘ arile accidentale, iar feedback-ul vizual oferit de ˘ afis, aj s,
i LED-uri completeaza experient ˘ | ,a de utilizare.
În Figura 5 este prezentata o randare ilustrativ ˘ | a a modului ˘
în care este organizata interfat ˘ | ,a fizica a sistemului de control ˘
al accesului. Aceasta reprezentare evident ˘ | ,

iaza integrarea com- ˘
ponentelor într-un ansamblu coerent, precum s,

i modul în care

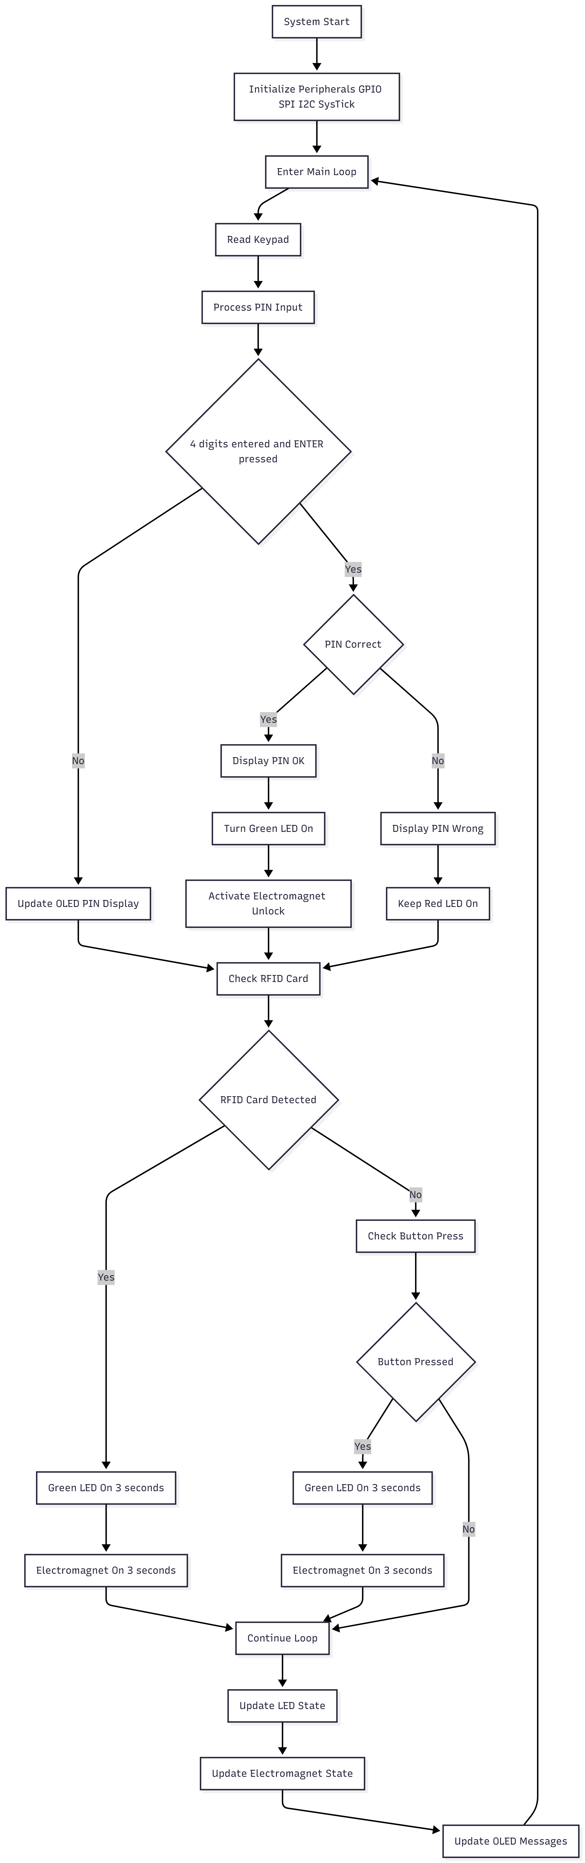
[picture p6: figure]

Figura 6. Diagrama de flux a buclei principale a sistemului de control al accesului

utilizatorul interact,

ioneaza cu dispozitivul în timpul procesului ˘ de autentificare.

Pe lânga rolul funct ˘ | ,
ional, interfat,a fizica contribuie s ˘ | ,
i la
percept,

ia de securitate a sistemului. Un panou clar organizat, cu elemente bine delimitate s,

i feedback vizual constant, inspira˘ încredere utilizatorului s,

i reduce posibilitatea utilizarii gres ˘ , ite
a dispozitivului. Astfel, designul interfet,ei fizice nu este doar un aspect estetic, ci o componenta esent ˘ ,

iala în asigurarea unei ˘
experient,e de utilizare sigure s,

i eficiente.

XII. MODUL DE COMUNICAT,

IE FRDM–WI-FI S,
I AFIS, ARE
LOGURI ÎN INTERFAT, A WEB ˘
Aceasta component ˘ | a software are rolul de a asigura pre- ˘
luarea mesajelor de stare generate de sistemul implementat pe placa FRDM, transmiterea acestora catre un modul Wi- ˘ Fi s,
i publicarea lor sub forma de loguri într-o interfat ˘ | | ,a web ˘
accesibila din ret ˘ | ,eaua locala.˘
Comunicarea dintre placa FRDM s,

i modulul Wi-Fi se
realizeaza indirect, prin intermediul unei pl ˘ | aci Arduino, care ˘
funct,
ioneaza ca unitate de interconectare s ˘ | ,
i procesare a me-
sajelor. Legatura FRDM–Arduino este realizat ˘ | a prin interfat ˘ | ,a˘
UART, iar Arduino controleaza modulul ESP8266 folosind ˘ comenzi AT, printr-o a doua interfat,a serial ˘ a.˘
Placa FRDM transmite mesaje text reprezentând rezultatul operat,

iilor efectuate de sistem, precum validarea unui card RFID sau verificarea unui cod PIN. Aceste mesaje sunt trimise prin UART la un baud rate de 9600 bps s,
i sunt recept,
| | ionate
de Arduino sub forma de s ˘ | ,
iruri de caractere terminate cu
caracter de linie noua. La recept ˘ | ,
ie, mesajele sunt procesate s,
i stocate într-o structura de tip buffer, care p ˘ | astreaz ˘ | a ultimele ˘
evenimente generate de sistem.
Pentru expunerea informat,

iilor catre utilizator, Arduino con- ˘
figureaza modulul ESP8266 în mod stat ˘ | ,
ie s,

i îl conecteaza la ˘
o ret,ea Wi-Fi existenta. Ulterior, modulul este configurat s ˘ | | a˘
funct,

ioneze ca server TCP/IP pe portul 80, permit,ând accesarea interfet,ei web printr-un browser standard. La detectarea
unei cereri HTTP, sistemul genereaza dinamic o pagin ˘ | | a HTML ˘
care cont,

ine logurile curente, afis, ate sub forma de tabel. ˘

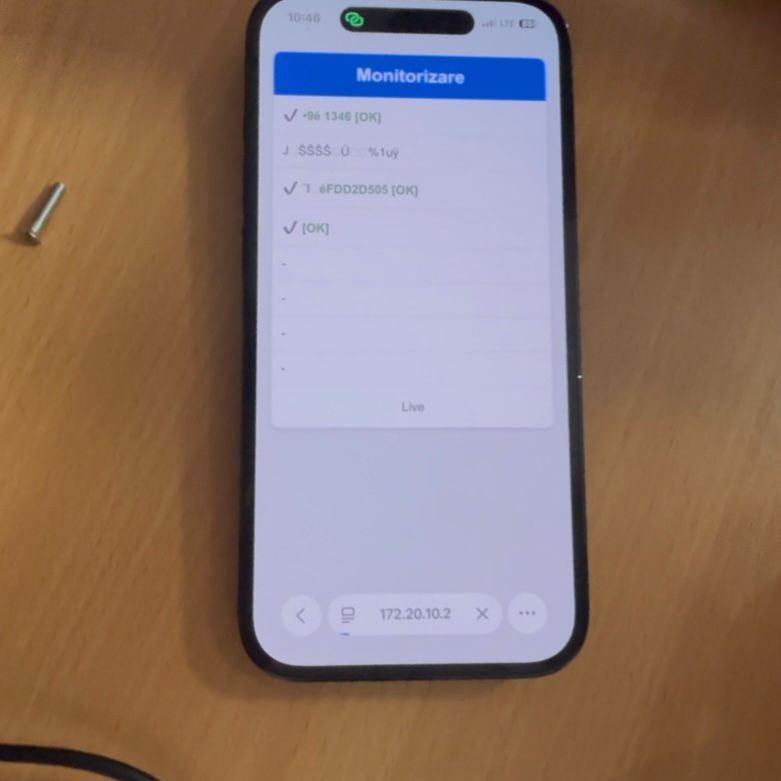
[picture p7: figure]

Figura 7. Interfat,a web pentru monitorizarea în timp real a evenimentelor sistemului

Pagina web este transmisa direct c ˘ | atre client prin cone- ˘
xiunea deschisa, folosind comenzi AT de trimitere a datelor. ˘ Evenimentele sunt evident,

iate vizual pentru a permite identi-
ficarea rapida a st ˘ | arilor de succes sau es ˘ | , ec. Dupa trimiterea ˘
cont,
inutului, conexiunea este închisa, iar sistemul r ˘ | amâne ˘
disponibil pentru cereri ulterioare.
Prin aceasta abordare, sistemul ofer ˘ | a o solut ˘ | ,
ie de monito-
rizare în timp real, far˘ a a necesita infrastructur ˘ | a suplimentar ˘ | a˘
sau servicii externe, permit,ând vizualizarea starii sistemului ˘

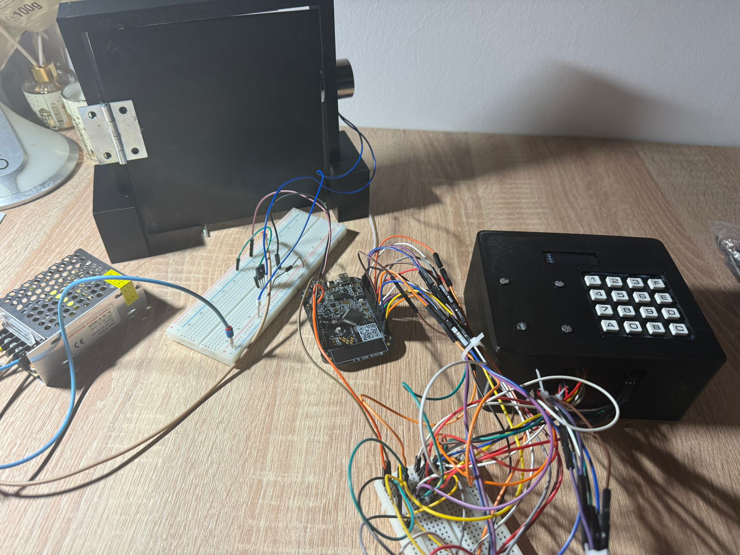
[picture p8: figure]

Figura 8. Prototipul fizic al sistemului – vedere frontala˘

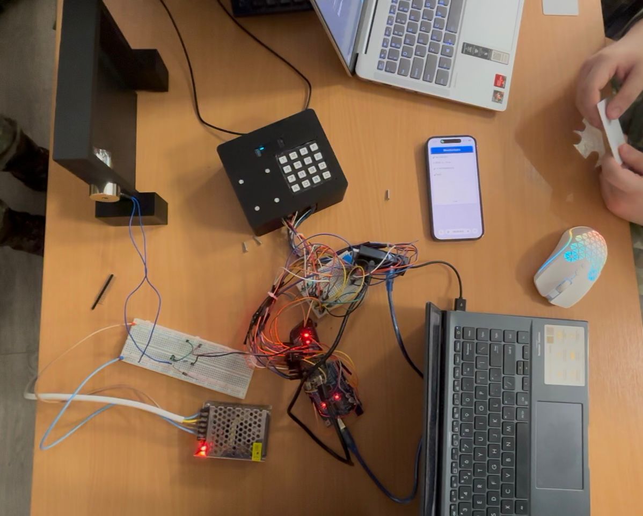
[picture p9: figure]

Figura 9. Prototipul fizic – integrarea componentelor hardware

direct dintr-un browser web, utilizând exclusiv comunicat,

ie
seriala s ˘ ,

i ret,ea locala Wi-Fi, conform exemplului ilustrat în ˘ Figura 7.

XIII. CONCLUZIE ASUPRA INTEGRARII SISTEMULUI ˘

Integrarea modulelor hardware s,

i software demonstreaza˘
realizarea unui sistem embedded complet, capabil sa imple- ˘ menteze un mecanism de control al accesului în doi pas,

i.
Fiecare componenta contribuie la funct ˘ | ,

ionalitatea globala:˘
- RFID — identificare far˘ a contact ˘
- Tastatura — autentificare suplimentar ˘ | a prin PIN ˘
- OLED — interfat,a om–mas ˘ | ,

ina˘
- LED-uri — feedback vizual instant
- Electromagnet — act,

ionare fizica a mecanismului de ˘ acces
- Buton — metoda alternativ ˘ | a de acces ˘
Prin coordonarea acestora prin firmware-ul microcontrolerului FRDM-KL25Z, sistemul obt,
ine un echilibru între securitate, fiabilitate s,

i simplitate arhitecturala, reprezentând o ˘ solut,

ie eficienta pentru aplicat ˘ | ,
ii reale de control al accesului. Pentru validarea designului mecanic realizat în Autodesk Fusion 360, a fost construit prototipul fizic al sistemului.
În figurile urmatoare este prezentat ˘ | a implementarea real ˘ | a a ˘
sistemului de control al accesului, evident,
| | iind integrarea com-
ponentelor electronice în carcasa proiectata.˘
| REFERINT, E
| BIBLIOGRAFIE
[1] J. J. Mortensen, M. Gjerding, and K. S. Thygesen, “MyQueue: Task and workflow scheduling system,” Journal of Open Source Software, vol. 5, no. 45, p. 1844, 2020.
[2] G. Eason, B. Noble, and I. N. Sneddon, “On certain integrals of Lipschitz-Hankel type involving products of Bessel functions,” Phil. Trans. Roy. Soc. London, vol. A247, pp. 529–551, April 1955.
[3] J. Clerk Maxwell, A Treatise on Electricity and Magnetism, 3rd ed., vol.
2. Oxford: Clarendon, 1892, pp.68–73.
[4] I. S. Jacobs and C. P. Bean, “Fine particles, thin films and exchange anisotropy,” in Magnetism, vol. III, G. T. Rado and H. Suhl, Eds. New York: Academic, 1963, pp. 271–350.
[5] K. Elissa, “Title of paper if known,” unpublished.
[6] R. Nicole, “Title of paper with only first word capitalized,” J. Name Stand. Abbrev., in press.
[7] Y. Yorozu, M. Hirano, K. Oka, and Y. Tagawa, “Electron spectroscopy studies on magneto-optical media and plastic substrate interface,” IEEE Transl. J. Magn. Japan, vol. 2, pp. 740–741, August 1987 [Digests 9th Annual Conf. Magnetics Japan, p. 301, 1982].
[8] M. Young, The Technical Writer’s Handbook. Mill Valley, CA: University Science, 1989.
[9] Trace-ID, ”Understanding an RFID tag datasheet.” https://www.trace-id.com/en/understanding-an-rfid-tag-datasheet/

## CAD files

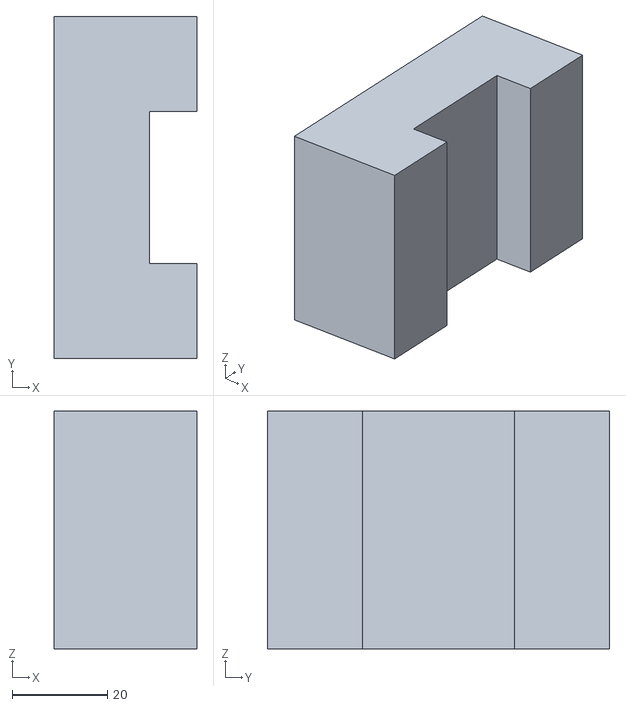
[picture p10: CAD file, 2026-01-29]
suport_usa_1.stl
30.0 x 72.0 x 50.0

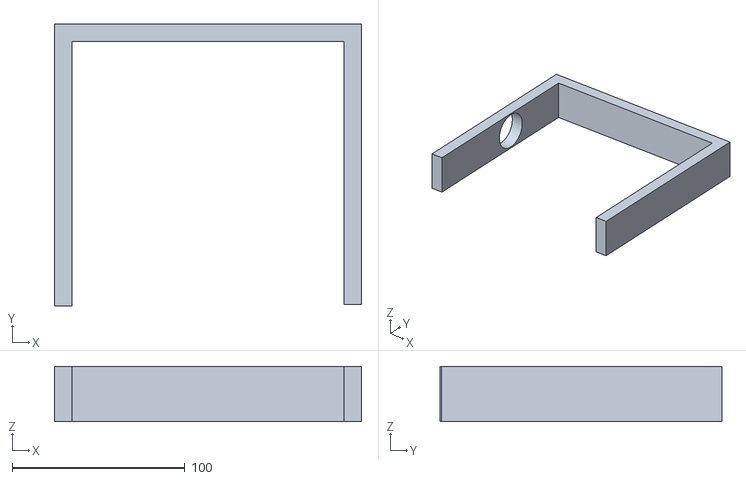
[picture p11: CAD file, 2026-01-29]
toc_deasupra_cu_gaura.stl
177.8 x 163.1 x 32.0

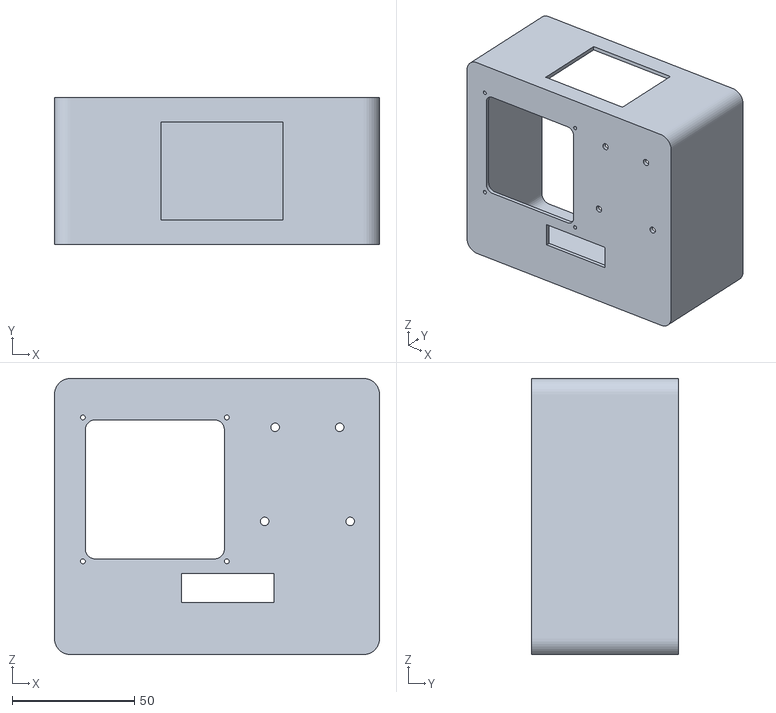
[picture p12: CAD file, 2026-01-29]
carcasa.stl
133.0 x 60.0 x 113.0

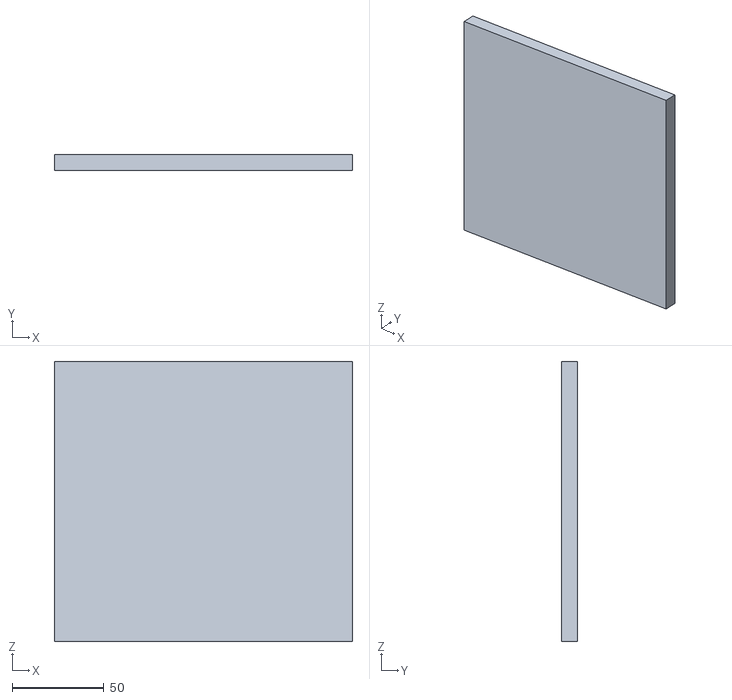
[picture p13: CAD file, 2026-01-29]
usa1.stl
162.5 x 8.88 x 152.7

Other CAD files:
suport_usa_2.stl

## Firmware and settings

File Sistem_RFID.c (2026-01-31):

#include "MKL25Z4.h"
#include <stdint.h>
#include <stdio.h> // Necesara pentru sprintf
#include "board.h"
#include "peripherals.h"
#include "pin_mux.h"
#include "clock_config.h"
#include "fsl_debug_console.h"

/* ================= SYSTICK ================= */
volatile uint32_t msTicks = 0;

void SysTick_Handler(void) {
    msTicks++;
}

static void delay_ms(uint32_t ms) {
    uint32_t start = msTicks;
    while ((msTicks - start) < ms) {}
}

/* ================= UART2 SERVER (MODIFICAT) ================= */
/* AICI ESTE FIX-UL PENTRU LOGURI */
static void UART2_Init_Send(void) {
    SIM->SCGC4 |= SIM_SCGC4_UART2_MASK;
    SIM->SCGC5 |= SIM_SCGC5_PORTE_MASK;

    // PTE22 = TX (Transmit)
    PORTE->PCR[22] = PORT_PCR_MUX(4);

    UART2->C2 &= ~(UART_C2_TE_MASK | UART_C2_RE_MASK);

    // Baud Rate 9600
    uint32_t bus_clock = CLOCK_GetBusClkFreq();
    uint32_t divisor = bus_clock / (16 * 9600);

    UART2->BDH = (divisor >> 8) & UART_BDH_SBR_MASK;
    UART2->BDL = (divisor & UART_BDL_SBR_MASK);

    UART2->C2 |= UART_C2_TE_MASK;
}

static void Send_Log(char *msg) {
    while(*msg) {
        while(!(UART2->S1 & UART_S1_TDRE_MASK));
        UART2->D = *msg++;
    }
}

// --- FIX: Trimite HEX manual ca sa nu apara caractere ciudate ---
// Aceasta functie transforma numarul (ex: 0xA4) in text ("A4")
static void Send_Hex_Byte(uint8_t byte) {
    char hexMap[] = "0123456789ABCDEF";

    // Trimitem prima cifra (High Nibble)
    while(!(UART2->S1 & UART_S1_TDRE_MASK));
    UART2->D = hexMap[(byte >> 4) & 0x0F];

    // Trimitem a doua cifra (Low Nibble)
    while(!(UART2->S1 & UART_S1_TDRE_MASK));
    UART2->D = hexMap[byte & 0x0F];
}

/* ================= RC522 PINS ================= */
#define RC522_CS_PIN     4   // PTC4
#define RC522_RST_PIN    0   // PTC0

/* ================= LED (active LOW) ================= */
#define LED_RED_PIN     18   // PTB18
#define LED_GREEN_PIN   19   // PTB19

/* ================= RC522 REGISTERS ================= */
#define CommandReg      0x01
#define ComIrqReg       0x04
#define ErrorReg        0x06
#define FIFODataReg     0x09
#define FIFOLevelReg    0x0A
#define BitFramingReg   0x0D
#define ModeReg         0x11
#define TxControlReg    0x14
#define TxASKReg        0x15
#define TModeReg        0x2A
#define TPrescalerReg   0x2B
#define TReloadRegH     0x2C
#define TReloadRegL     0x2D
#define PICC_ANTICOLL   0x93

/* ================= RC522 COMMANDS ================= */
#define PCD_IDLE        0x00
#define PCD_TRANSCEIVE  0x0C
#define PCD_RESETPHASE  0x0F
#define PICC_REQIDL     0x26

/* ================= KEYPAD 4x4 ================= */
#define KP_ROW0 5   // PTD5
#define KP_ROW1 0   // PTD0
#define KP_ROW2 2   // PTD2
#define KP_ROW3 3   // PTD3

#define KP_COL0 7   // PTD7
#define KP_COL1 13  // PTA13
#define KP_COL2 0   // PTE0
#define KP_COL3 1   // PTE1

static const char keymap[4][4] = {
    {'1','2','3','F'},
    {'4','5','6','E'},
    {'7','8','9','D'},
    {'A','0','B','C'}   // C = Enter
};

#define ENTER_KEY 'C'
#define RESET_KEY 'A'
static const char PIN_CODE[5] = "1346";

/* ================= OLED SSD1306 (I2C1) ================= */
#define OLED_I2C_ADDR   0x3C
#define SSD1306_PAGES   4

/* ================= BUTTON ================= */
#define BUTTON_PIN  3   // PTC3

/* ================= ELECTROMAGNET ================= */
#define MAGNET_PIN   2

/* ================= LED timer (verde 3 sec) ================= */
volatile uint32_t led_green_until = 0;

static void LED_Init(void) {
    SIM->SCGC5 |= SIM_SCGC5_PORTB_MASK;
    PORTB->PCR[LED_RED_PIN]   = PORT_PCR_MUX(1);
    PORTB->PCR[LED_GREEN_PIN] = PORT_PCR_MUX(1);
    PTB->PDDR |= (1u << LED_RED_PIN) | (1u << LED_GREEN_PIN);
    PTB->PSOR |= (1u << LED_RED_PIN) | (1u << LED_GREEN_PIN); // off
}

static void LED_Red(void) {
    PTB->PCOR = (1u << LED_RED_PIN);
    PTB->PSOR = (1u << LED_GREEN_PIN);
}

static void LED_Green(void) {
    PTB->PCOR = (1u << LED_GREEN_PIN);
    PTB->PSOR = (1u << LED_RED_PIN);
}

static inline void LED_Green_3s(void) {
    LED_Green();
    led_green_until = msTicks + 3000;
}

static inline void LED_Update(void) {
    if ((int32_t)(msTicks - led_green_until) >= 0) {
        LED_Red();
    }
}

/* ================= ELECTROMAGNET ================= */
static void Magnet_Init(void)
{
    SIM->SCGC5 |= SIM_SCGC5_PORTC_MASK;

    PORTC->PCR[MAGNET_PIN] = PORT_PCR_MUX(1);  // GPIO
    PTC->PDDR |= (1u << MAGNET_PIN);           // output

    // implicit OFF (Magnet blocat)
    PTC->PCOR = (1u << MAGNET_PIN);
}

static inline void Magnet_On(void)
{
    PTC->PCOR = (1u << MAGNET_PIN);
}

static inline void Magnet_Off(void)
{
    PTC->PSOR = (1u << MAGNET_PIN);
}

static inline void Magnet_Update(void)
{
    // dacă încă suntem în fereastra de verde => ON (Deschis)
    if ((int32_t)(msTicks - led_green_until) < 0) {
        Magnet_On();
    } else {
        Magnet_Off();
    }
}


/* ================================================= */
/* ================= SPI0 (RC522) ================== */
/* ================================================= */
static void SPI0_Init(void) {
    SIM->SCGC5 |= SIM_SCGC5_PORTC_MASK;
    SIM->SCGC4 |= SIM_SCGC4_SPI0_MASK;

    PORTC->PCR[5] = PORT_PCR_MUX(2); // SCK
    PORTC->PCR[6] = PORT_PCR_MUX(2); // MOSI
    PORTC->PCR[7] = PORT_PCR_MUX(2); // MISO

    SPI0->C1 = SPI_C1_MSTR_MASK;
    SPI0->C2 = 0;
    SPI0->BR = SPI_BR_SPPR(3) | SPI_BR_SPR(8); // ~500kHz
    SPI0->C1 |= SPI_C1_SPE_MASK;
}

static uint8_t SPI0_Transfer(uint8_t data) {
    while (!(SPI0->S & SPI_S_SPTEF_MASK)) {}
    SPI0->D = data;
    while (!(SPI0->S & SPI_S_SPRF_MASK)) {}
    return SPI0->D;
}

/* ================= RC522 GPIO ================= */
static inline void RC522_CS_LOW(void)  { PTC->PCOR = (1u << RC522_CS_PIN); }
static inline void RC522_CS_HIGH(void) { PTC->PSOR = (1u << RC522_CS_PIN); }

static void RC522_GPIO_Init(void) {
    SIM->SCGC5 |= SIM_SCGC5_PORTC_MASK;

    PORTC->PCR[RC522_CS_PIN] = PORT_PCR_MUX(1);
    PTC->PDDR |= (1u << RC522_CS_PIN);
    RC522_CS_HIGH();

    PORTC->PCR[RC522_RST_PIN] = PORT_PCR_MUX(1);
    PTC->PDDR |= (1u << RC522_RST_PIN);
    PTC->PSOR |= (1u << RC522_RST_PIN);
}

static void RC522_Reset(void) {
    PTC->PCOR |= (1u << RC522_RST_PIN);
    for (volatile int i = 0; i < 10000; i++) {}
    PTC->PSOR |= (1u << RC522_RST_PIN);
}

/* ================= RC522 REG I/O ================= */
static void RC522_WriteReg(uint8_t reg, uint8_t value) {
    RC522_CS_LOW();
    SPI0_Transfer((reg << 1) & 0x7E);
    SPI0_Transfer(value);
    RC522_CS_HIGH();
}

static uint8_t RC522_ReadReg(uint8_t reg) {
    uint8_t val;
    RC522_CS_LOW();
    SPI0_Transfer(((reg << 1) & 0x7E) | 0x80);
    val = SPI0_Transfer(0x00);
    RC522_CS_HIGH();
    return val;
}

/* ================= RC522 INIT ================= */
static void RC522_Init(void) {
    RC522_Reset();
    RC522_WriteReg(CommandReg, PCD_RESETPHASE);
    for (volatile int i = 0; i < 100000; i++) {}

    RC522_WriteReg(TModeReg, 0x8D);
    RC522_WriteReg(TPrescalerReg, 0x3E);
    RC522_WriteReg(TReloadRegL, 30);
    RC522_WriteReg(TReloadRegH, 0);

    RC522_WriteReg(TxASKReg, 0x40);
    RC522_WriteReg(ModeReg, 0x3D);

    RC522_WriteReg(TxControlReg, RC522_ReadReg(TxControlReg) | 0x03);
}

/* ================= CARD REQUEST ================= */
static uint8_t RC522_Request(uint8_t *atqa) {
    uint8_t irq;
    uint8_t fifo;

    RC522_WriteReg(BitFramingReg, 0x07);
    RC522_WriteReg(CommandReg, PCD_IDLE);
    RC522_WriteReg(FIFOLevelReg, 0x80);

    RC522_WriteReg(FIFODataReg, PICC_REQIDL);
    RC522_WriteReg(CommandReg, PCD_TRANSCEIVE);
    RC522_WriteReg(BitFramingReg, 0x87);

    for (int i = 0; i < 3000; i++) {
        irq = RC522_ReadReg(ComIrqReg);
        if (irq & 0x20) break;
        if (irq & 0x01) return 0;
    }

    if (RC522_ReadReg(ErrorReg) & 0x1B) return 0;

    fifo = RC522_ReadReg(FIFOLevelReg);
    if (fifo != 2) return 0;

    atqa[0] = RC522_ReadReg(FIFODataReg);
    atqa[1] = RC522_ReadReg(FIFODataReg);
    return 1;
}

// === FUNCTIE NOUA: CITESTE UID-UL CARDULUI ===
static uint8_t RC522_Anticoll(uint8_t *uid) {
    RC522_WriteReg(BitFramingReg, 0x00);
    RC522_WriteReg(FIFOLevelReg, 0x80);
    RC522_WriteReg(FIFODataReg, PICC_ANTICOLL);
    RC522_WriteReg(FIFODataReg, 0x20);
    RC522_WriteReg(CommandReg, 0x0C);
    RC522_WriteReg(BitFramingReg, 0x80);

    for(int i=0; i<2000; i++) {
        if(RC522_ReadReg(ComIrqReg) & 0x20) {
            // Am primit date, citim UID
            for(int j=0; j<5; j++) uid[j] = RC522_ReadReg(FIFODataReg);
            return 1;
        }
    }
    return 0;
}

/* ================================================= */
/* ================= KEYPAD ========================= */
/* ================================================= */
static inline void rows_all_high(void) {
    PTD->PSOR = (1u << KP_ROW0) | (1u << KP_ROW1) | (1u << KP_ROW2) | (1u << KP_ROW3);
}
static inline void row_low(uint32_t rpin) { PTD->PCOR = (1u << rpin); }

static inline uint32_t col_read_by_index(int col) {
    switch (col) {
        case 0: return (PTD->PDIR & (1u << KP_COL0)) ? 1u : 0u;
        case 1: return (PTA->PDIR & (1u << KP_COL1)) ? 1u : 0u;
        case 2: return (PTE->PDIR & (1u << KP_COL2)) ? 1u : 0u;
        case 3: return (PTE->PDIR & (1u << KP_COL3)) ? 1u : 0u;
        default: return 1u;
    }
}

static void Keypad_Init(void) {
    SIM->SCGC5 |= SIM_SCGC5_PORTD_MASK | SIM_SCGC5_PORTA_MASK | SIM_SCGC5_PORTE_MASK;

    PORTD->PCR[KP_ROW0] = PORT_PCR_MUX(1);
    PORTD->PCR[KP_ROW1] = PORT_PCR_MUX(1);
    PORTD->PCR[KP_ROW2] = PORT_PCR_MUX(1);
    PORTD->PCR[KP_ROW3] = PORT_PCR_MUX(1);

    PORTD->PCR[KP_COL0] = PORT_PCR_MUX(1) | PORT_PCR_PE_MASK | PORT_PCR_PS_MASK;
    PORTA->PCR[KP_COL1] = PORT_PCR_MUX(1) | PORT_PCR_PE_MASK | PORT_PCR_PS_MASK;
    PORTE->PCR[KP_COL2] = PORT_PCR_MUX(1) | PORT_PCR_PE_MASK | PORT_PCR_PS_MASK;
    PORTE->PCR[KP_COL3] = PORT_PCR_MUX(1) | PORT_PCR_PE_MASK | PORT_PCR_PS_MASK;

    PTD->PDDR |= (1u << KP_ROW0) | (1u << KP_ROW1) | (1u << KP_ROW2) | (1u << KP_ROW3);
    PTD->PDDR &= ~(1u << KP_COL0);
    PTA->PDDR &= ~(1u << KP_COL1);
    PTE->PDDR &= ~((1u << KP_COL2) | (1u << KP_COL3));

    rows_all_high();
}



static char Keypad_GetKey(void) {
    const uint32_t rows[4] = { KP_ROW0, KP_ROW1, KP_ROW2, KP_ROW3 };

    for (int r = 0; r < 4; r++) {
        rows_all_high();
        row_low(rows[r]);

        for (volatile int k = 0; k < 200; k++) {}

        for (int c = 0; c < 4; c++) {
            if (col_read_by_index(c) == 0u) {
                delay_ms(15);
                if (col_read_by_index(c) == 0u) {
                    char ch = keymap[r][c];
                    while (col_read_by_index(c) == 0u) {}
                    delay_ms(10);
                    return ch;
                }
            }
        }
    }
    return 0;
}



//============= BUTTON ======================
static void Button_Init(void)
{
    SIM->SCGC5 |= SIM_SCGC5_PORTC_MASK;

    PORTC->PCR[BUTTON_PIN] =
        PORT_PCR_MUX(1) |   // GPIO
        PORT_PCR_PE_MASK |  // pull enable
        PORT_PCR_PS_MASK;   // pull-up

    PTC->PDDR &= ~(1u << BUTTON_PIN); // input
}


static inline int Button_Pressed(void)
{
    return ((PTC->PDIR & (1u << BUTTON_PIN)) == 0); // LOW = apăsat
}


/* ================================================= */
/* ================= I2C1 (OLED) ==================== */
/* ================================================= */
static void I2C1_Init(void) {
    SIM->SCGC5 |= SIM_SCGC5_PORTC_MASK;
    SIM->SCGC4 |= SIM_SCGC4_I2C1_MASK;

    PORTC->PCR[10] = PORT_PCR_MUX(2) | (1u << 5);
    PORTC->PCR[11] = PORT_PCR_MUX(2) | (1u << 5);

    I2C1->F  = I2C_F_MULT(0) | I2C_F_ICR(0x14); // ~100kHz
    I2C1->C1 = I2C_C1_IICEN_MASK;
}

static void I2C1_WaitBusFree(void)
{
    uint32_t t0 = msTicks;
    while (I2C1->S & I2C_S_BUSY_MASK) {
        if ((msTicks - t0) > 20) break;
    }
}

static void I2C1_Start(void)
{
    I2C1_WaitBusFree();
    I2C1->C1 |= I2C_C1_TX_MASK;
    I2C1->C1 |= I2C_C1_MST_MASK;
}

static void I2C1_Stop(void)
{
    I2C1->C1 &= ~I2C_C1_MST_MASK;
    I2C1->C1 &= ~I2C_C1_TX_MASK;
    for (volatile int i=0; i<200; i++) {}
}

static int I2C1_WriteByte(uint8_t b)
{
    I2C1->S |= I2C_S_IICIF_MASK;
    I2C1->D = b;
    uint32_t t0 = msTicks;
    while (!(I2C1->S & I2C_S_IICIF_MASK)) {
        if ((msTicks - t0) > 10) return 0;
    }
    I2C1->S |= I2C_S_IICIF_MASK;
    if (I2C1->S & I2C_S_RXAK_MASK) return 0;
    if (I2C1->S & I2C_S_ARBL_MASK) {
        I2C1->S |= I2C_S_ARBL_MASK;
        return 0;
    }
    return 1;
}

static int I2C1_WriteBytes(uint8_t addr7, const uint8_t *data, uint32_t len)
{
    I2C1_Start();
    if (!I2C1_WriteByte((addr7 << 1) | 0)) { I2C1_Stop(); return 0; }
    for (uint32_t i = 0; i < len; i++) {
        if (!I2C1_WriteByte(data[i])) { I2C1_Stop(); return 0; }
    }
    I2C1_Stop();
    return 1;
}

static void I2C_Scan(void)
{
    PRINTF("I2C scan...\r\n");
    for (uint8_t a = 1; a < 0x7F; a++) {
        I2C1_Start();
        if (I2C1_WriteByte((a << 1) | 0)) {
            PRINTF("ACK at 0x%02X\r\n", a);
        }
        I2C1_Stop();
        delay_ms(2);
    }
    PRINTF("Scan done.\r\n");
}

/* ================= SSD1306 ================= */
static void SSD1306_Cmd(uint8_t cmd)
{
    uint8_t pkt[2] = {0x00, cmd};
    if (!I2C1_WriteBytes(OLED_I2C_ADDR, pkt, 2)) {
        delay_ms(300);
    }
}

static void SSD1306_Data(const uint8_t *data, uint32_t len) {
    uint8_t buf[17];
    buf[0] = 0x40;
    while (len) {
        uint32_t chunk = (len > 16) ? 16 : len;
        for (uint32_t i = 0; i < chunk; i++) buf[1+i] = data[i];
        I2C1_WriteBytes(OLED_I2C_ADDR, buf, chunk + 1);
        data += chunk;
        len  -= chunk;
    }
}

static void SSD1306_SetCursor(uint8_t x, uint8_t page) {
    SSD1306_Cmd(0xB0 | (page & 0x03));
    SSD1306_Cmd(0x00 | (x & 0x0F));
    SSD1306_Cmd(0x10 | ((x >> 4) & 0x0F));
}

static void SSD1306_Clear(void) {
    for (uint8_t page = 0; page < SSD1306_PAGES; page++) {
        SSD1306_SetCursor(0, page);
        for (uint8_t col = 0; col < 128; col++) {
            uint8_t z = 0x00;
            SSD1306_Data(&z, 1);
        }
    }
    SSD1306_SetCursor(0, 0);
}

static void SSD1306_Init(void) {
    delay_ms(50);
    SSD1306_Cmd(0xAE);
    SSD1306_Cmd(0xD5); SSD1306_Cmd(0x80);
    SSD1306_Cmd(0xA8); SSD1306_Cmd(0x1F);
    SSD1306_Cmd(0xD3); SSD1306_Cmd(0x00);
    SSD1306_Cmd(0x40);
    SSD1306_Cmd(0x8D); SSD1306_Cmd(0x14);
    SSD1306_Cmd(0x20); SSD1306_Cmd(0x00);
    SSD1306_Cmd(0xA1);
    SSD1306_Cmd(0xC8);
    SSD1306_Cmd(0xDA); SSD1306_Cmd(0x02);
    SSD1306_Cmd(0x81); SSD1306_Cmd(0x7F);
    SSD1306_Cmd(0xD9); SSD1306_Cmd(0xF1);
    SSD1306_Cmd(0xDB); SSD1306_Cmd(0x40);
    SSD1306_Cmd(0xA4);
    SSD1306_Cmd(0xA6);
    SSD1306_Cmd(0xAF);

    SSD1306_Clear();
    SSD1306_SetCursor(0,0);
}

/* ===== FONT ===== */
static const uint8_t font5x7[][5] = {
    {0x00,0x00,0x00,0x00,0x00}, // ' '
    {0x00,0x36,0x36,0x00,0x00}, // ':'
    {0x14,0x08,0x3E,0x08,0x14}, // '*'
    {0x3E,0x51,0x49,0x45,0x3E}, // 0
    {0x00,0x42,0x7F,0x40,0x00}, // 1
    {0x42,0x61,0x51,0x49,0x46}, // 2
    {0x21,0x41,0x45,0x4B,0x31}, // 3
    {0x18,0x14,0x12,0x7F,0x10}, // 4
    {0x27,0x45,0x45,0x45,0x39}, // 5
    {0x3C,0x4A,0x49,0x49,0x30}, // 6
    {0x01,0x71,0x09,0x05,0x03}, // 7
    {0x36,0x49,0x49,0x49,0x36}, // 8
    {0x06,0x49,0x49,0x29,0x1E}, // 9
    {0x7E,0x11,0x11,0x11,0x7E}, // A
    {0x7F,0x49,0x49,0x49,0x36}, // B
    {0x3E,0x41,0x41,0x41,0x22}, // C
    {0x7F,0x41,0x41,0x22,0x1C}, // D
    {0x7F,0x49,0x49,0x49,0x41}, // E
    {0x7F,0x09,0x09,0x09,0x01}, // F
};

static const uint8_t GLYPH_P[5] = {0x7F,0x09,0x09,0x09,0x06}; // P
static const uint8_t GLYPH_I[5] = {0x00,0x41,0x7F,0x41,0x00}; // I
static const uint8_t GLYPH_N[5] = {0x7F,0x02,0x04,0x08,0x7F}; // N
static const uint8_t GLYPH_O[5] = {0x3E,0x41,0x41,0x41,0x3E}; // O
static const uint8_t GLYPH_K[5] = {0x7F,0x08,0x14,0x22,0x41}; // K
static const uint8_t GLYPH_R[5] = {0x7F,0x09,0x19,0x29,0x46}; // R
static const uint8_t GLYPH_W[5] = {0x7F,0x20,0x18,0x20,0x7F}; // W
static const uint8_t GLYPH_G[5] = {0x3E,0x41,0x49,0x49,0x3A}; // G
static const uint8_t GLYPH_Y[5] = {0x07,0x08,0x70,0x08,0x07}; // Y

static const uint8_t* glyph(char c)
{
    if (c == ' ') return font5x7[0];
    if (c == ':') return font5x7[1];
    if (c == '*') return font5x7[2];
    if (c >= '0' && c <= '9') return font5x7[3 + (c - '0')];
    if (c >= 'A' && c <= 'F') return font5x7[13 + (c - 'A')];
    if (c == 'P') return GLYPH_P;
    if (c == 'I') return GLYPH_I;
    if (c == 'N') return GLYPH_N;
    if (c == 'O') return GLYPH_O;
    if (c == 'K') return GLYPH_K;
    if (c == 'R') return GLYPH_R;
    if (c == 'W') return GLYPH_W;
    if (c == 'G') return GLYPH_G;
    if (c == 'Y') return GLYPH_Y;
    return font5x7[0];
}

static void SSD1306_WriteChar(char c) {
    uint8_t out[6];
    const uint8_t *g = glyph(c);
    out[0]=g[0]; out[1]=g[1]; out[2]=g[2]; out[3]=g[3]; out[4]=g[4];
    out[5]=0x00;
    SSD1306_Data(out, 6);
}

static void SSD1306_WriteString(const char *s) {
    while (*s) SSD1306_WriteChar(*s++);
}

/* ================= OLED helper ================= */

volatile uint32_t oled_msg_until = 0;
volatile uint8_t  oled_showing_msg = 0;
static void OLED_ShowPIN(uint8_t count) {
    SSD1306_Clear();
    SSD1306_SetCursor(0,0);
    SSD1306_WriteString("PIN: ");
    for (uint8_t i = 0; i < count; i++) SSD1306_WriteChar('*');
}
static void OLED_ClearLine(uint8_t page)
{
    SSD1306_SetCursor(0, page);
    uint8_t zeros[16];
    for (int i = 0; i < 16; i++) zeros[i] = 0x00;
    for (int blk = 0; blk < 8; blk++) {
        SSD1306_Data(zeros, 16);
    }
}

static void OLED_ShowPIN_Buffer(const char *buf)
{
    OLED_ClearLine(0);
    SSD1306_SetCursor(0, 0);
    SSD1306_WriteString("PIN: ");
    SSD1306_WriteString(buf);
}

static void OLED_ShowMessageTimed(const char *msg, uint32_t ms)
{
    OLED_ClearLine(2);
    SSD1306_SetCursor(0, 2);
    SSD1306_WriteString(msg);
    oled_showing_msg = 1;
    oled_msg_until = msTicks + ms;
}
static void OLED_Update(void)
{
    if (!oled_showing_msg) return;
    if ((int32_t)(msTicks - oled_msg_until) >= 0) {
        oled_showing_msg = 0;
        OLED_ClearLine(2);
    }
}

static void OLED_WriteLine(uint8_t page, const char *text)
{
    OLED_ClearLine(page);
    SSD1306_SetCursor(0, page);
    SSD1306_WriteString(text);
}

/* ================================================= */
/* ================= PIN LOGIC ====================== */
/* ================================================= */
static inline int is_digit(char ch) { return (ch >= '0' && ch <= '9'); }
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
int main(void) {
    BOARD_InitBootPins();
    BOARD_InitBootClocks();
    BOARD_InitBootPeripherals();
    #ifndef BOARD_INIT_DEBUG_CONSOLE_PERIPHERAL
    BOARD_InitDebugConsole();
    #endif

    SysTick_Config(SystemCoreClock / 1000);

    // Initializari Hardware
    SPI0_Init();
    RC522_GPIO_Init();
    RC522_Init();
    LED_Init();
    Keypad_Init();
    Button_Init();
    Magnet_Init();

    // Initializare UART (Server)
    UART2_Init_Send();

    // Secventa de start
    LED_Init();
    LED_Red();
    delay_ms(200);
    LED_Green();
    delay_ms(200);
    LED_Red();

    I2C1_Init();
    I2C_Scan();

    LED_Green();
    delay_ms(200);
    LED_Red();

    SSD1306_Init();
    OLED_ShowPIN_Buffer("1234");
    OLED_WriteLine(2, "PIN OK");
    LED_Green();
    delay_ms(200);
    LED_Red();
    OLED_ShowPIN(0);

    PRINTF("Ready\r\n");

    uint8_t atqa[2];
    uint8_t uid[5]; // Pentru ID-ul cardului
    char pinbuf[5] = {0};
    uint8_t pinidx = 0;

    LED_Red();

    while (1) {
        char k = Keypad_GetKey();
        PIN_ProcessKey(k, pinbuf, &pinidx);

        // --- MODIFICARE AICI: CITIRE UID + LOG + USA ---
        if (RC522_Request(atqa)) {
            // Daca detectam card, incercam sa citim si ID-ul
            if(RC522_Anticoll(uid)) {
                // 1. Deschide usa (Magnet + LED)
                LED_Green_3s();

                // 2. Afiseaza pe OLED
                OLED_ShowMessageTimed("CARD ACCES", 2000);

                // 3. Trimite LOG detaliat catre Arduino (MANUAL HEX)
                Send_Log("CARD:");
                Send_Hex_Byte(uid[0]);
                Send_Hex_Byte(uid[1]);
                Send_Hex_Byte(uid[2]);
                Send_Hex_Byte(uid[3]);
                Send_Log(" [OK]\n"); // Linie noua la final

                // 4. Pauza mica sa nu citeasca de 100 de ori
                delay_ms(1000);
                RC522_Init(); // Re-initializare necesara
            }
        }

        // --- UPDATE PENTRU ACTUATORI ---
        LED_Update();
        Magnet_Update();
        OLED_Update();

        if (Button_Pressed()) {
            LED_Green_3s();

            // Optional: Log pentru buton
            Send_Log("BUTON: EXIT [OK]\n");

            while (Button_Pressed()) {} // așteaptă eliberarea
        }

    }
}

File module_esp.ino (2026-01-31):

#include <SoftwareSerial.h>

// ==========================================
// CONFIGURARE WIFI (VERIFICA SA FIE CORECTE)
// ==========================================
String AP_SSID = "DIGI-DFFFA";     
String AP_PASS = "cyberman1234";   
// ==========================================

SoftwareSerial frdm(8, 9); // RX, TX
SoftwareSerial esp(2, 3);  // RX, TX

const int MAX_LOGS = 8;
String logs[MAX_LOGS]; 

void setup() {
  Serial.begin(9600);
  frdm.begin(9600);
  esp.begin(9600);

  for(int i=0; i<MAX_LOGS; i++) logs[i] = "-";

  Serial.println(F("--- START SYSTEM DIAGNOSTIC ---"));
  
  // 1. Resetare ESP
  Serial.println(F("1. Resetare ESP..."));
  sendCmd(F("AT+RST\r\n"), 3000);
  sendCmd(F("AT+CWMODE=1\r\n"), 1000);
  
  // 2. Conectare
  Serial.print(F("2. Conectare la ")); Serial.println(AP_SSID);
  String cmd = "AT+CWJAP=\"" + AP_SSID + "\",\"" + AP_PASS + "\"\r\n";
  esp.print(cmd);
  
  // Asteptam maxim 15 secunde conectarea
  long start = millis();
  while(millis() - start < 15000) {
    while(esp.available()) {
      char c = esp.read();
      // Serial.write(c); // Uncomment daca vrei sa vezi tot ce zice ESP
    }
  }
  
  // 3. Configurare Server
  Serial.println(F("3. Pornire Server..."));
  sendCmd(F("AT+CIPMUX=1\r\n"), 1000);
  sendCmd(F("AT+CIPSERVER=1,80\r\n"), 1000);
  
  Serial.println(F("\n--------------------------------"));
  Serial.println(F("SISTEM ONLINE! Verifica IP-ul mai jos:"));
  sendCmd(F("AT+CIFSR\r\n"), 1000);
  Serial.println(F("--------------------------------"));
  
  esp.listen();
}

void loop() {
  // ----------------------------------------
  // 1. VERIFICAM FRDM (CARD/PIN)
  // ----------------------------------------
  frdm.listen();
  delay(20); 
  
  if (frdm.available()) {
    String raw = frdm.readStringUntil('\n');
    raw.trim();
    if (raw.length() > 3) {
      Serial.print("LOG PRIMIT: ");
      Serial.println(raw); // Debug in consola
      addLog(raw);
    }
  }

  // ----------------------------------------
  // 2. VERIFICAM WEB (ESP)
  // ----------------------------------------
  esp.listen();
  delay(20);
  
  if (esp.available()) {
    if (esp.find("+IPD,")) {
      delay(300); // Asteptam sa intre cererea
      int id = esp.read() - 48;
      
      // Golim bufferul (ignoram request-ul lung)
      while(esp.available()) esp.read();
      
      Serial.println(F("Browser conectat! Trimit pagina..."));
      
      // === TRIMITERE PAGINA (FARA VERIFICARI > CA SA NU SE BLOCHEZE) ===
      
      // 1. Header (Se spune browserului ca e HTML)
      sendData(id, F("HTTP/1.1 200 OK\r\nContent-Type: text/html\r\nConnection: close\r\nRefresh: 5\r\n\r\n"));
      
      // 2. CSS + Start HTML
      String head = F("<!DOCTYPE html><html><head><meta name='viewport' content='width=device-width, initial-scale=1'>");
      head += F("<style>body{font-family:Arial,sans-serif;background:#eee;padding:10px}.box{background:#fff;border-radius:10px;padding:0;overflow:hidden;box-shadow:0 2px 5px rgba(0,0,0,0.1)}");
      head += F("h2{background:#007bff;color:#fff;margin:0;padding:15px;text-align:center}table{width:100%;border-collapse:collapse}td{padding:12px;border-bottom:1px solid #eee}");
      head += F(".ok{color:green;font-weight:bold}.fail{color:red;font-weight:bold}</style></head><body>");
      sendString(id, head);

      // 3. Tabel Start
      sendData(id, F("<div class='box'><h2>Monitorizare</h2><table>"));
      
      // 4. Logurile
      for(int i=0; i<MAX_LOGS; i++) {
        String row = "<tr>";
        if(logs[i].indexOf("OK") >= 0) row += "<td class='ok'>&#10004; " + logs[i] + "</td>";
        else if(logs[i].indexOf("FAIL") >= 0) row += "<td class='fail'>&#10060; " + logs[i] + "</td>";
        else row += "<td>" + logs[i] + "</td>";
        row += "</tr>";
        
        sendString(id, row);
      }
      
      // 5. Footer
      sendData(id, F("</table><p style='text-align:center;color:#777'>Live</p></div></body></html>"));
      
      // 6. Inchidere
      String close = "AT+CIPCLOSE=" + String(id) + "\r\n";
      esp.print(close);
      
      Serial.println(F("Gata! Pagina trimisa."));
    }
  }
}

// Functie "Oarba" (Blind Send) - Trimite fara sa astepte confirmare (Mai sigur pt blocaje)
void sendData(int id, const __FlashStringHelper* data) {
  esp.print("AT+CIPSEND=");
  esp.print(id);
  esp.print(",");
  esp.println(strlen_P((const char*)data));
  delay(200); // Pauza fixa - ESP are timp sa proceseze
  esp.print(data);
  delay(100); 
}

void sendString(int id, String data) {
  esp.print("AT+CIPSEND=");
  esp.print(id);
  esp.print(",");
  esp.println(data.length());
  delay(200); // Pauza fixa
  esp.print(data);
  delay(100);
}

void addLog(String newLog) {
  for (int i = MAX_LOGS - 1; i > 0; i--) logs[i] = logs[i - 1];
  logs[0] = newLog;
}

void sendCmd(const __FlashStringHelper* cmd, int wait) {
  esp.print(cmd);
  delay(wait);
  while(esp.available()) Serial.write(esp.read());
}

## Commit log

2026-01-29 Adaugare stl-uri ale componentelor printate 3d
    [carcasa.stl, suport_usa_1.stl, suport_usa_2.stl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]
2026-01-31 Add files via upload
    Fisiere Cod FRDM+ARDUINO
